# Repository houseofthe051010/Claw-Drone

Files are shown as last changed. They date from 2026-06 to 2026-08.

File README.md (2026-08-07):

# Claw Drone

Claw Drone

This is a payload quadcopter with four continuous-rotation claw
servos to grab objects. I build a custom controller with
two joysticks, trim buttons, a TFT dashboard, and direct claw controls.
The transmitter uses ESPNOW long range to send CRSF commands at 200hz, where another RX es32 onboard converts them into CRSF for the FC to interpret.

I built this as a way to further myself in the knowledge of drones and aerial payload delivery.

The CAD, BOM, and FIRMWARE for both the controller and the drone are in this repo

This project started with an esp32 as the FC, but later changed to using a conventional ESC+FC stack.

## Demo

[Watch the competition flight demo on YouTube](https://youtube.com/shorts/Rw3jiggKQBY)

## System architecture

```text
Joysticks and buttons
        |
        v
Black Pill Pico-compatible board -- UART 115200 --> Controller ESP32-WROOM
                                           |
                                           | ESP-NOW LR, channel 6
                                           v
                                    Drone ESP32-WROOM
                                      |           |
                           CRSF UART3 |           | 4 x 50 Hz PWM
                                      v           v
                              Betaflight FC    Claw servos
                                      |
                                      v
                                ESC and motors
```

## Wiring schematics

### Handheld controller schematic

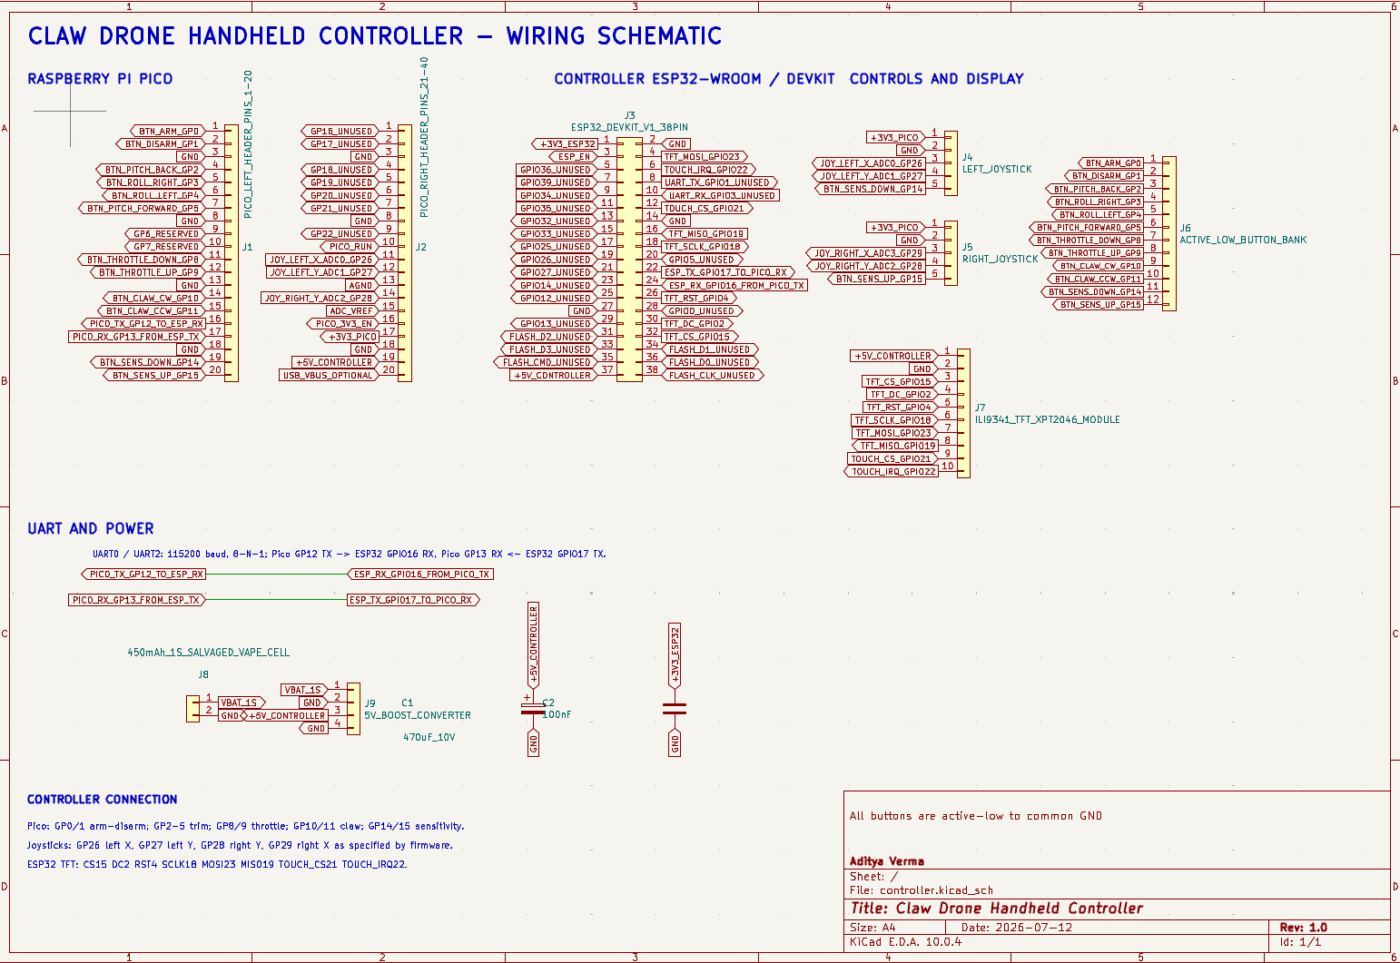
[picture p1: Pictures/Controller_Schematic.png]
Handheld controller wiring schematic


### Aircraft schematic

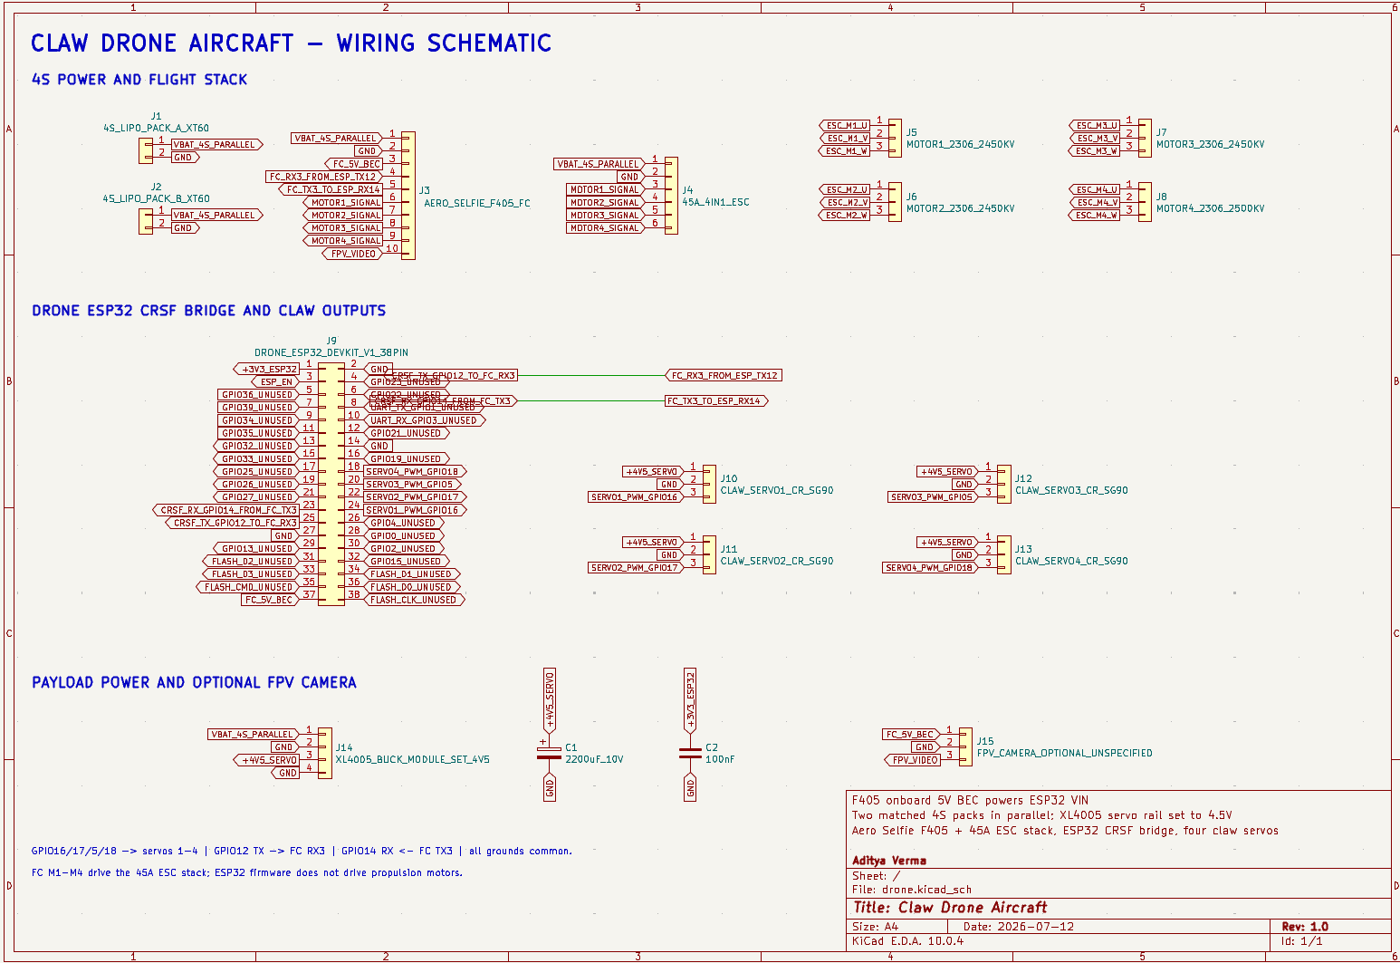
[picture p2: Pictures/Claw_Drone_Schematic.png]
Aircraft wiring schematic


## Bill of materials

| Assembly |  Quantity | Part | Purchase Link | Estimated Price |
| --- | ---: | --- | --- | ---: |
| Aircraft | 1 | Frame | [AliExpress](https://www.aliexpress.us/item/3256811569379527.html) | $17.06 |
| Aircraft | 1 | FC + ESC stack | [AliExpress](https://www.aliexpress.us/item/3256808946065124.html) | $49.63 |
| Aircraft | 4 | Brushless motors | [AliExpress](https://www.aliexpress.us/item/3256812458735650.html) | $61.36 |
| Aircraft | 1 set | Propellers | [AliExpress](https://www.aliexpress.us/item/2255801043927518.html) | $15.25 |
| Aircraft | 2 | Flight batteries | [AliExpress](https://www.aliexpress.us/item/3256812540292605.html) | $30.34 |
| Aircraft | 1 | XT60 connectors | [AliExpress](https://www.aliexpress.us/item/3256807605726245.html) | $1.77 |
| Aircraft | 1 | ESP32 | [AliExpress](https://www.aliexpress.us/item/3256808984038785.html) | $4.84 |
| Aircraft | 4 | Servos | [AliExpress](https://www.aliexpress.us/item/3256809795714797.html) | $3.63 used |
| Aircraft | 1 | XL4005 buck converter | [AliExpress](https://www.aliexpress.us/item/3256806558389509.html) | $1.46 |
| Aircraft | 1 | Camera | [AliExpress](https://www.aliexpress.us/item/3256810060131517.html) | $25.90 |
| Aircraft | 1 | 3D-printing allowance | [AliExpress](https://www.aliexpress.us/item/3256806989098121.html) | $2.54 |
| Aircraft | As needed | Wiring | [AliExpress](https://www.aliexpress.us/item/3256809610137308.html) | $5.49 allowance |
| Aircraft | As needed | Connectors | [AliExpress](https://www.aliexpress.us/item/3256804089626824.html) | $3.81 assortment kit |
| Controller | 1 | Raspberry Pi Pico | [AliExpress](https://www.aliexpress.us/item/3256805910466139.html) | $4.35 |
| Controller | 1 | ESP32 | [AliExpress](https://www.aliexpress.us/item/3256808984038785.html) | $4.84 |
| Controller | 1 | TFT touchscreen display | [AliExpress](https://www.aliexpress.us/item/2255800128937536.html) | $10.87 |
| Controller | 2 | Joystick modules | [AliExpress](https://www.aliexpress.us/item/3256809884616435.html) | $5.76 |
| Controller | 10 | Pushbuttons | [AliExpress](https://www.aliexpress.us/item/3256801710165519.html) | $3.32 |
| Controller | 1 | Controller battery | [AliExpress](https://www.aliexpress.us/item/3256809090690409.html) | $4.24 |
| Controller | 1 | Boost converter | [AliExpress](https://www.aliexpress.us/item/3256810344563800.html) | $0.99 |
| Controller | 1 | TP4056 charger module | [AliExpress](https://www.aliexpress.us/item/3256808777213556.html) | $0.20 used |
| Controller | 1 | Power switch | [AliExpress](https://www.aliexpress.us/item/3256807619399290.html) | $0.16 used |
| Controller | 1 | Bulk capacitor | [AliExpress](https://www.aliexpress.us/item/2251832671851361.html) | $0.10 used |
| Controller | 1 | Decoupling capacitor | [AliExpress](https://www.aliexpress.us/item/3256811560978404.html) | $0.01 used |
| Controller | 1 | Controller filament allowance | [AliExpress](https://www.aliexpress.us/item/3256806989098121.html) | $3.04 |
| Controller | As needed | Wiring | [AliExpress](https://www.aliexpress.us/item/3256809610137308.html) | $5.49 allowance |

## Assembly process

### Print settings

The prototype was printed in PETG on an Anycubic Kobra S1 using 100% infill,
10 walls, and a 0.2 mm layer height. The printable files are in
[`CAD/Individual STL files`](CAD/Individual%20STL%20files), with matching STEP
exports in [`CAD/Individual STEP files`](CAD/Individual%20STEP%20files).

Use [Building Your First 5-Inch FPV Drone: A Complete Step-by-Step Guide](https://blog.uavmodel.com/building-your-first-5-inch-fpv-drone-a-complete-step-by-step-guide/) for the standard FPV frame/motor/ESC+FC stack guide.

### Aircraft build

1. Build it like a normal FPV frame, like the one in the video above
  * If you have a commercial FPV frame that will work, otherwise print the frame pieces in the INDIVIDUAL STLs

2. Parallel battery connection
 
Solder two XT60 connectors; you don't even need to do this if you don't want to, as it only increases flight time while increasing weight too. Keep following what the demo video does if you don't want a parallel connection. If you do then you have to solder two XT60 wires to the ESC -/+ pads.

3. Standard FPV connections
Plug the ESP32 U.FL Wroom into the F405 5 V BEC and common ground.
This is your version of the "ELRS" the demo ideo will be talking about. Connect TX3/RX3 to esp32 RX2/TX2.
Also, for the camera you won't be using that 5.8ghz or DJI O4 mini. You will use the xiao S3 mini cam, and connect the 5V BEC and common gnd just like you did with the RX esp32.

4. Four-servos claw
3D print four SG90 mount holders and install one beneath each motor holder.
 * This is inside the Additional Attachment individual STLs, print the mirrored and normal servo claw attachment twice (4 total)
 * Also print the servo mounts to mount them with the motor mounts
Install the 10mm M3s to mount them and secure each SG90 servo to its printed holder with the self-tapping screws.
Route the servo cables along the arms to the inside. Secure them outside the motor and propeller area with zip ties.
Connect all four servo positive wires to XL4005 OUT+, and all four grounds to OUT-. Connect the PWM control lines as servo 1 – GPIO16, servo 2 – GPIO17, servo 3 – GPIO5, and servo 4 – GPIO18.

5. XL4005 claw power supply
Connect XL4005 IN+ directly to the ESC BAT+ pad and IN- to BAT-.
Make sure to set the voltage to 4.5v Connect all four servos to a common gnd with the esp32.

### Handheld controller build

1. Enclosure preparation
Print all of the INDIVIDUAL STLs, get soldering iron, flux, and a ton of thin 32AWG wire

2. Controller power supply
Mount the LIPO cell with glue.
Mount the TP4056 next to its usb port hole on the case
Connect the battery to TP4056 B+ and B-. Then, connect TP4056 OUT+ to the main toggle switch, while OUT- connects to controller ground.
Make sure its outputting 5v

3. Controller boards and antenna
Position the Black Pill board right behind the USB opening of the enclosure.
Apply glue to the flat underside of the board to mount it there.
Mount the controller ESP32 right to the left of the Black Pill board using adhesive on its flat side.
The UART connection runs from Black Pill GP12 TX to ESP32 GPIO16 RX and from Black Pill GP13 RX to ESP32 GPIO17 TX.
Install the U.FL antenna, and glue it to the top center opening.

4. Buttons
Use superglue to secure buttons.
Daisy change the grounds (easiest way to avoid messy wiring)
Connect the other terminals to their respective pi pico GPIO

5. Joysticks
Secure each joystick in its four mounting holes
Connect their 3.3/GND to pi pico, and their ADC pins to the assigned ADC gpio.

6. TFT display
Solder the ESP32 to the TFT as CS GPIO15, DC GPIO2, RST GPIO4, SCLK GPIO18, MOSI GPIO23, MISO GPIO19, touch CS GPIO21, and touch IRQ GPIO22.
TFT power connects to the regulated 5V rail.
Mount it with M3 x 25 mm screws, and route its wires to the left of the pi pico (make sure they are short or it will be hard).

## Controller pinout

USE THIS WHEN BUILDING THE CONTROLLER/DRONE

### Black Pill Picoboard

Note that you have to be using a black pill pico with 4 ADC inputs instead of 3 like the normal pi pico.

| Pico pin | Connection |
| --- | --- |
| GP0 | Button to GND |
| GP1 | Button to GND |
| GP2 | Button to GND |
| GP3 | Button to GND |
| GP4 | Button to GND |
| GP5 | Button to GND |
| GP6 | Not used |
| GP7 | Not used |
| GP8 | Button to GND |
| GP9 | Button to GND |
| GP10 | Button to GND |
| GP11 | Button to GND |
| GP12 | ESP32 GPIO16 |
| GP13 | ESP32 GPIO17 |
| GP14 | Left stick button |
| GP15 | Right stick button |
| GP25 | Onboard LED |
| GP26 / ADC0 | Left joystick X |
| GP27 / ADC1 | Left joystick Y |
| GP28 / ADC2 | Right joystick Y |
| GP29 / ADC3 | Right joystick X |
| 3V3 | Joystick VCC |
| GND | All controller grounds |

### Pico to controller ESP32 UART

| Black Pill Pico-compatible board | Controller ESP32-WROOM |
| --- | --- |
| GP12 UART0 TX | GPIO16 UART2 RX |
| GP13 UART0 RX | GPIO17 UART2 TX |
| GND | GND |

### Controller TFT and touch

| Display signal | Controller ESP32 GPIO |
| --- | --- |
| TFT CS | GPIO15 |
| TFT DC | GPIO2 |
| TFT RST | GPIO4 |
| SPI SCLK | GPIO18 |
| SPI MOSI | GPIO23 |
| SPI MISO | GPIO19 |
| Touch CS | GPIO21 |
| Touch IRQ | GPIO22 |
| GND | GND |

## Four-leg claw system

You have to use the self tapping screws that came with the sg90 to mount them.

1. Legs spread from the center creating area around the payload.
2. All four legs move out from under the motors.

## Drone pinout

### Drone ESP32 to Betaflight flight controller

| Drone ESP32-WROOM | Flight controller |
| --- | --- |
| GPIO12 UART2 TX | RX3 |
| GPIO14 UART2 RX | TX3 |
| GND | GND |

UART setup for CRSF protocol.

### Drone ESP32 servo outputs

| Servo | PWM signal pin |
| --- | --- |
| Servo 1 | ESP32 GPIO16 |
| Servo 2 | ESP32 GPIO17 |
| Servo 3 | ESP32 GPIO5 |
| Servo 4 | ESP32 GPIO18 |

The FC did not have enough motor outputs to drive servos so I used the onboard ESP32.

### Servo power

Servos are powered by the XL4005 buck converter at 4.5V

## Setting up the code

Use the PlatformIO extension in VScode to flash, configure this repo with it and run this in terminal:

### Flashing the controller ESP32

```sh
cd Code/controller/esp32_tx
pio run -t upload
pio device monitor
```

### Flashing the drone ESP32

```sh
cd Code/drone/esp32_rx
pio run -t upload
pio device monitor
```

Flash using micropython for the rpi, flash it with thonny using main.py code from Code/controller/pico/main.py

On the drone use ESP-IDF, the flight controller uses betaflight

The code is in the repo folder

Every ESP32 has different values for this: 

| Device | Wi-Fi STA MAC |
| --- | --- |
| Controller ESP32 | `68:09:47:5c:04:c4` |
| Drone ESP32 | `68:09:47:5c:2f:8c` |

Update both hard-coded peer addresses as per your devices.

* `drone_mac` in
  `Code/controller/esp32_tx/main/main.c`
* `controller_mac` in
  `Code/drone/esp32_rx/main/main.c`

## Betaflight setup

Give CRSF on UART3 with this configuration:

```text
serial 1 0 115200 57600 0 115200
serial 2 64 115200 57600 0 115200
set serialrx_provider = CRSF
set serialrx_inverted = OFF
set serialrx_halfduplex = OFF
save
```

| CRSF channel | Function |
| --- | --- |
| CH1 | Roll |
| CH2 | Pitch |
| CH3 | Throttle |
| CH4 | Yaw |
| CH5 / AUX1 | Arm |
| CH6 / AUX2 | Link-active indication |

ARM mode uses AUX1.

## Design and build process

### 1. Early arm concepts

First design concept was X-frame design with 5-DoF arm.
It has been dropped because of the arm mass. Second design concept was a
frame with electronics placed near its perimeter, and an opening in its center like a DONUT.
Through this opening, servo-controlled rope and spring mechanism were going
to clamp the payload. This was abandoned though as it interfered with the rotor thrust.

### 2. Lightweight claw redesign

I had four servos underneath, and initially a 5 dof arm as the claw.

Early claw prototype

Redesigned claw CAD

### 3. ESP32 flight-controller experiment

I used a esp32 supermini S3 but there were problems with the ESC connection and FC espnow connection leading me to abondon it.

ESP32 and ESC development

### 4. Moving flight control to Betaflight

Switched from ESP32 FC + cheap rc airplane ESCs to conventional drone stack.

Flight-controller stack

### 5. Building the custom transmitter

NRF24L01 were used at first but I switched to ESPNOW as its less wiring and reliable.

Transmitter wiring

Completed transmitter

### 6. Final assembly

Everything connected together

Final electronics assembly

Drone with claw installed

## What I would change next time\

* Improve the claw mehanism
* Have a single strong motor for the claw
* Increase drone size
* Have a much more robust FC

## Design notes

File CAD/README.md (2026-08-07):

# CAD files

## Print settings

The prototype was printed in PETG on an Anycubic Kobra S1 using:

- 100% infill
- 10 walls
- 0.2 mm layer height

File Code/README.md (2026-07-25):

# Firmware

```text
controller/
  pico/
    main.py              Reads controls and sends framed UART packets
  esp32_tx/
    main/main.c          UART bridge, ESP-NOW, servo web server
    main/dashboard.c     TFT dashboard and telemetry display
drone/
  esp32_rx/
    main/main.c          ESP-NOW receiver, CRSF output, servo PWM
diagnostics/
  pico_joystick_button_test/
    main.py              Standalone Pico input test
```

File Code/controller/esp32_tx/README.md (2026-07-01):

# Controller ESP32: Pico UART to ESP-NOW

This is the controller-side ESP32-WROOM bridge.

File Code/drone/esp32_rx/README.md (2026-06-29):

# Drone ESP32: ESP-NOW to CRSF receiver

This is the drone-side receiver. It receives control frames over
ESP-NOW and outputs CRSF RC frames to the flight controller.

Wiring:

| ESP32 WROOM | Flight controller |
| --- | --- |
| GPIO12 TX | FC RX3 |
| GPIO14 RX | FC TX3 |
| GND | GND |

Both ESP32s use unicast ESP-NOW on Wi-Fi channel 6 with Espressif Long Range
PHY at 250 Kbit/s. The transmitter is configured for this receiver's STA MAC:
`68:09:47:5c:2f:8c`.

The FC TX3 return wire is parsed for CRSF battery sensor frames. Valid battery
voltage and remaining-capacity percentage are returned to controller STA MAC
`68:09:47:5c:04:c4` over ESP-NOW for the TFT dashboard. No estimate is shown
when the FC does not provide a valid battery telemetry frame.

This firmware drives four direct ESP32 servo outputs at 50 Hz. They start
centered at 1500 us:

| Servo | ESP32 GPIO |
| --- | --- |
| Servo 1 | GPIO16 |
| Servo 2 | GPIO17 |
| Servo 3 | GPIO5 |
| Servo 4 | GPIO18 |

The matching transmitter web interface sends separate CRC-protected continuous
servo packets. Each output accepts 500-2500 us and applies a new pulse width
immediately. Saved neutral values and the selected 10-500 us rotation stretch
are stored in NVS and restored before PWM starts after a reboot. If servo
commands stop for 1.5 seconds, every output returns to its saved neutral value.

Betaflight UART3 configuration:

```text
serial 1 0 115200 57600 0 115200
serial 2 64 115200 57600 0 115200
set serialrx_provider = CRSF
set serialrx_inverted = OFF
set serialrx_halfduplex = OFF
save
```

`GPIO12` is an ESP32 boot-strapping pin. The FC RX input should be
high-impedance, but an external pull-up on this signal can prevent the ESP32
from booting. If that occurs, disconnect GPIO12 during reset or move CRSF TX
to a non-strapping GPIO and update `CRSF_TX_PIN`.

Build/flash:

```sh
cd Code/drone/esp32_rx
pio run -t upload
pio device monitor
```

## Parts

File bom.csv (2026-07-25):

Assembly | Quantity | Part | Link | Price
Aircraft | 1 | frame | https://www.aliexpress.us/item/3256811569379527.html | $17.06
Aircraft | 1 | FC+ESC stack | https://www.aliexpress.us/item/3256808946065124.html | $49.63
Aircraft | 4 | Brushless motor | https://www.aliexpress.us/item/3256812458735650.html | $61.36
Aircraft | 1 set | Propellers | https://www.aliexpress.us/item/2255801043927518.html | $15.25
Aircraft | 2 | Flight battery | https://www.aliexpress.us/item/3256812540292605.html | $30.34
Aircraft | 1 | XT60 connectors | https://www.aliexpress.us/item/3256807605726245.html | $1.77
Aircraft | 1 | ESP32 | https://www.aliexpress.us/item/3256808984038785.html | $4.84
Aircraft | 4 | servo | https://www.aliexpress.us/item/3256809795714797.html | $3.63 used (4 of 5-pack at $4.54)
Aircraft | 1 | XL4005 buck | https://www.aliexpress.us/item/3256806558389509.html | $1.46
Aircraft | 1 | Camera | https://www.aliexpress.us/item/3256810060131517.html | $25.90
Aircraft | 1 | 3d print allowance | https://www.aliexpress.us/item/3256806989098121.html | $2.54
Aircraft | as needed | wiring | https://www.aliexpress.us/item/3256809610137308.html | $5.49 allowance
Aircraft | as needed | connectors | https://www.aliexpress.us/item/3256804089626824.html | $3.81 assortment kit
Controller | 1 | pi pico | https://www.aliexpress.us/item/3256805910466139.html | $4.35
Controller | 1 | ESP32 | https://www.aliexpress.us/item/3256808984038785.html | $4.84
Controller | 1 | TFT touch display | https://www.aliexpress.us/item/2255800128937536.html | $10.87
Controller | 2 | Joystick module | https://www.aliexpress.us/item/3256809884616435.html | $5.76
Controller | 10 | pushbutton | https://www.aliexpress.us/item/3256801710165519.html | $3.32
Controller | 1 | Controller battery | https://www.aliexpress.us/item/3256809090690409.html | $4.24
Controller | 1 | Boost converter | https://www.aliexpress.us/item/3256810344563800.html | $0.99
Controller | 1 | TP4056 | https://www.aliexpress.us/item/3256808777213556.html | $0.20 used
Controller | 1 | power switch | https://www.aliexpress.us/item/3256807619399290.html | $0.16 used
Controller | 1 | Bulk capacitor | https://www.aliexpress.us/item/2251832671851361.html | $0.10 used
Controller | 1 | Decoupling capacitor | https://www.aliexpress.us/item/3256811560978404.html | $0.01 used
Controller | 1 | Controller filament allowance | https://www.aliexpress.us/item/3256806989098121.html | $3.04
Controller | as needed | wiring | https://www.aliexpress.us/item/3256809610137308.html | $5.49 allowance

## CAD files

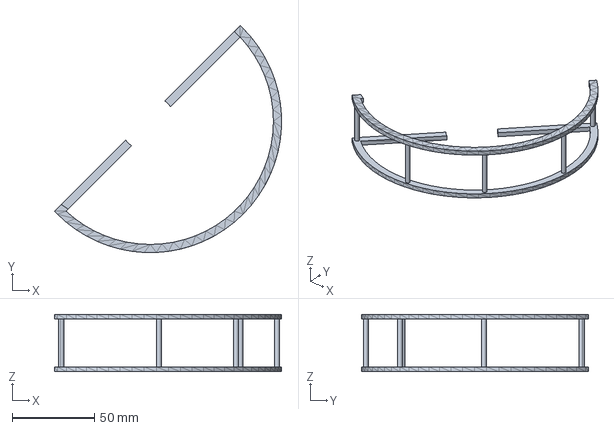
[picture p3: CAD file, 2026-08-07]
CAD/Individual STEP files/Attachment Parts/PROP_GUARD.step
138.3 x 138.3 x 35.0 mm

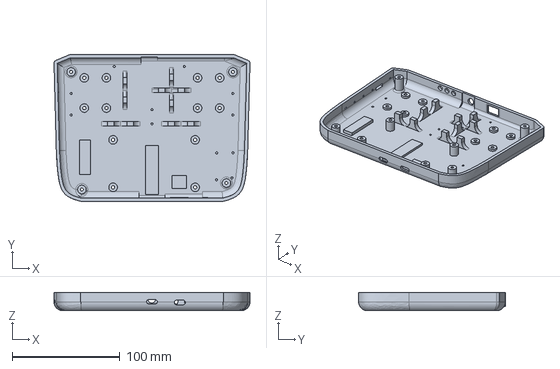
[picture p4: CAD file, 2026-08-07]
CAD/Individual STEP files/Controller/Bottom Plate.step
181.7 x 136.0 x 17.0 mm

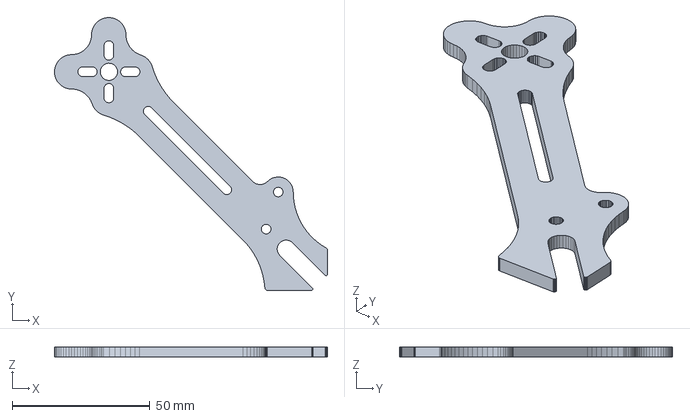
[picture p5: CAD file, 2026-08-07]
CAD/Individual STEP files/Drone Frame/Frame Arm (3).step
99.0 x 99.0 x 3.50 mm

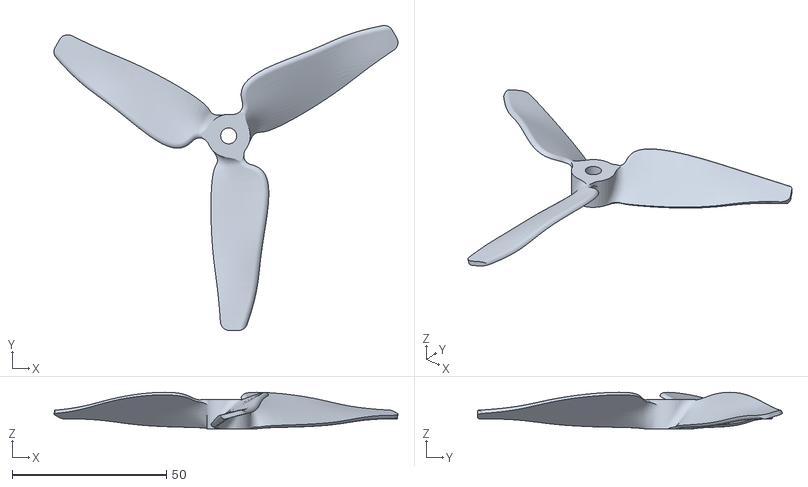
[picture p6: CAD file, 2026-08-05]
CAD/Individual STL files/Attachment Parts/5 inch propellors.stl
111.4 x 98.7 x 11.8

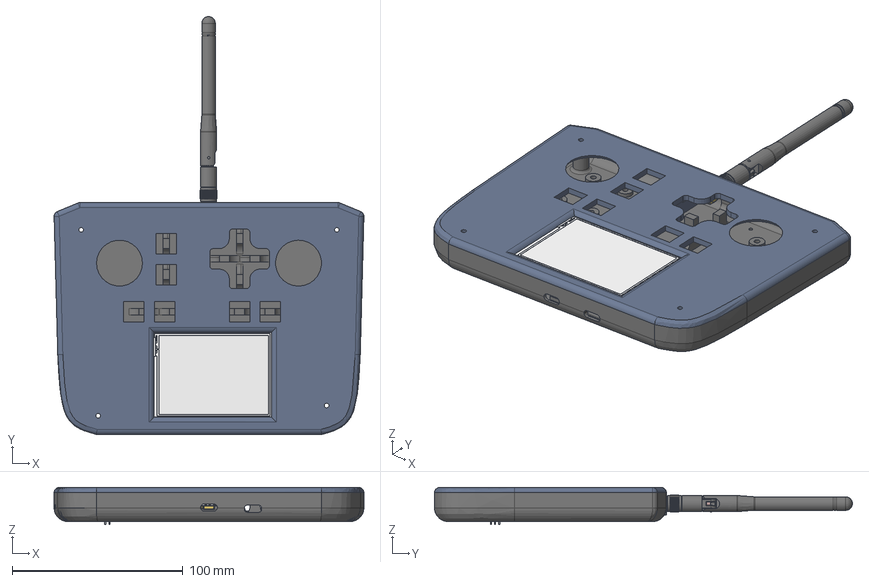
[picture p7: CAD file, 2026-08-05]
CAD/SOURCE Cad/Drone Controller.step
181.7 x 245.2 x 21.7 mm

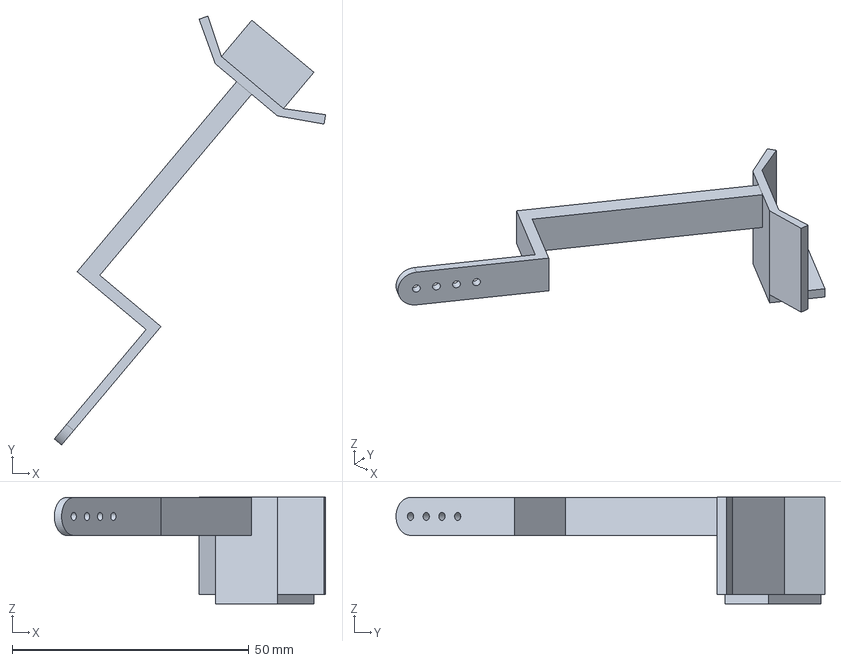
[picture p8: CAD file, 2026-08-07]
CAD/Individual STEP files/Attachment Parts/Servo Claw Attachment Pt2 (Mirrored).step
57.3 x 90.6 x 22.5 mm

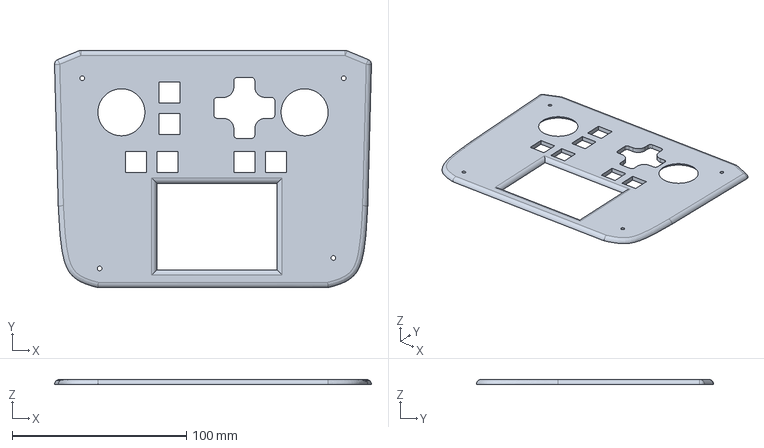
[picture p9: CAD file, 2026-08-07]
CAD/Individual STEP files/Controller/Top Plate.step
181.7 x 136.0 x 3.00 mm

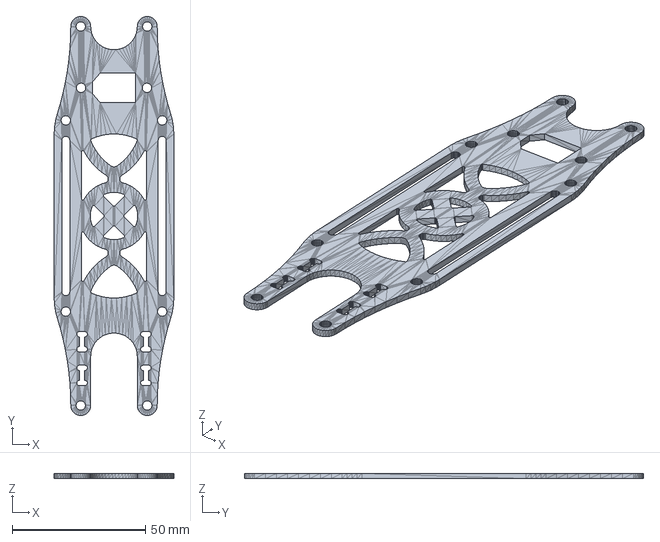
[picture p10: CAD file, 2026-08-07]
CAD/Individual STEP files/Drone Frame/Bottom Plate.step
45.0 x 150.0 x 2.00 mm

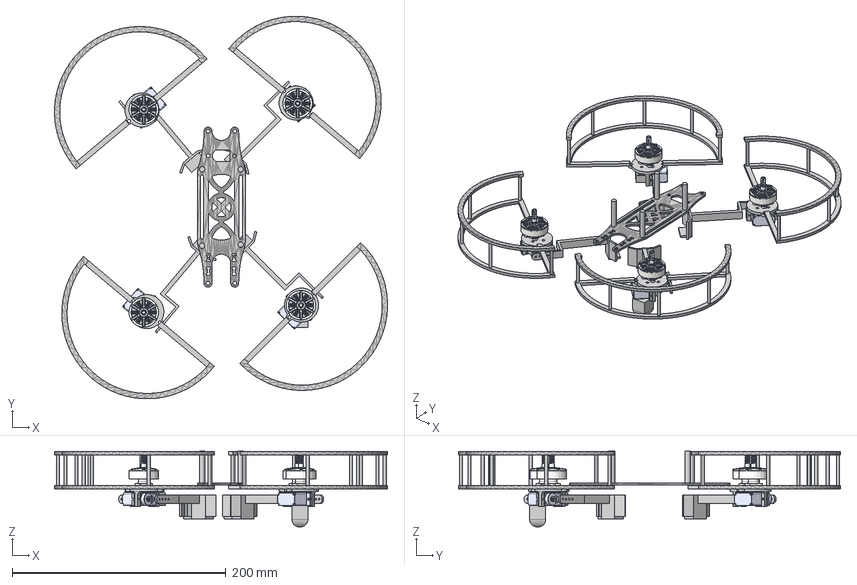
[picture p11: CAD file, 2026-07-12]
CAD/SOURCE Cad/Claw Drone.step
311.9 x 358.2 x 71.1 mm

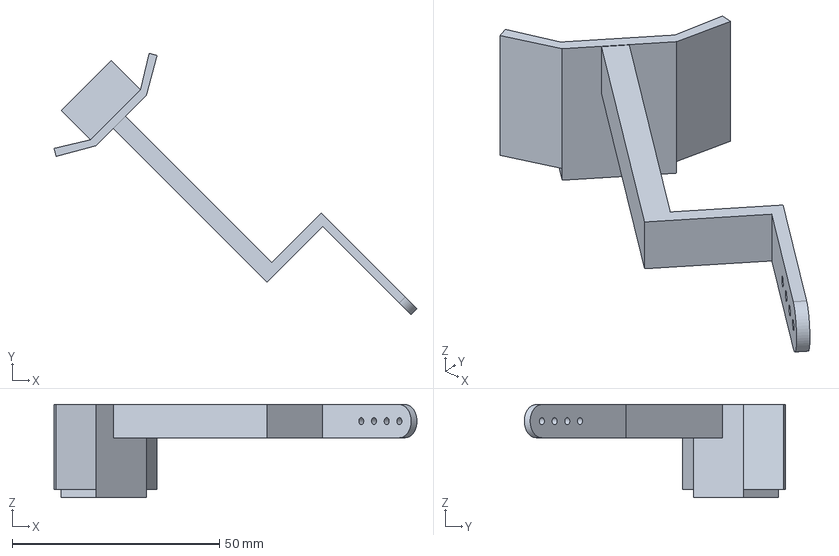
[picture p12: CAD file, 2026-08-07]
CAD/Individual STEP files/Attachment Parts/Servo Claw Attachment Pt1.step
87.5 x 63.0 x 22.5 mm

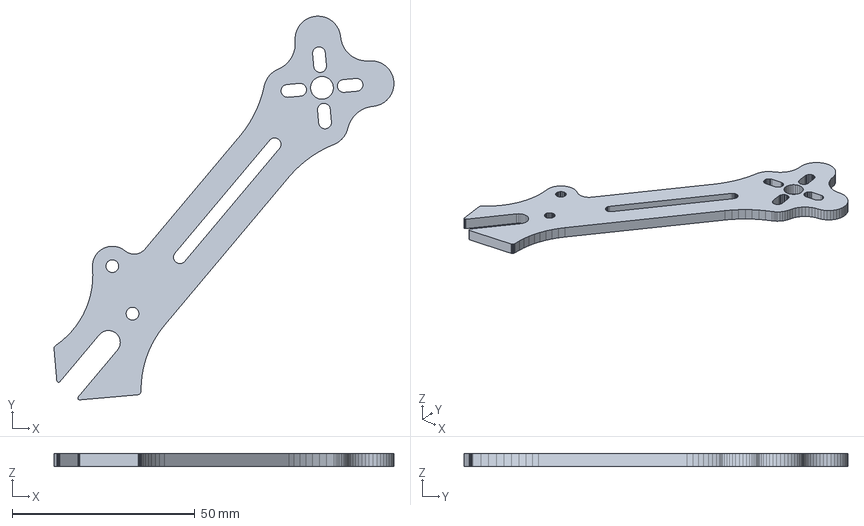
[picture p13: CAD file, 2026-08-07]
CAD/Individual STEP files/Drone Frame/Frame Arm (2).step
93.1 x 105.0 x 3.50 mm

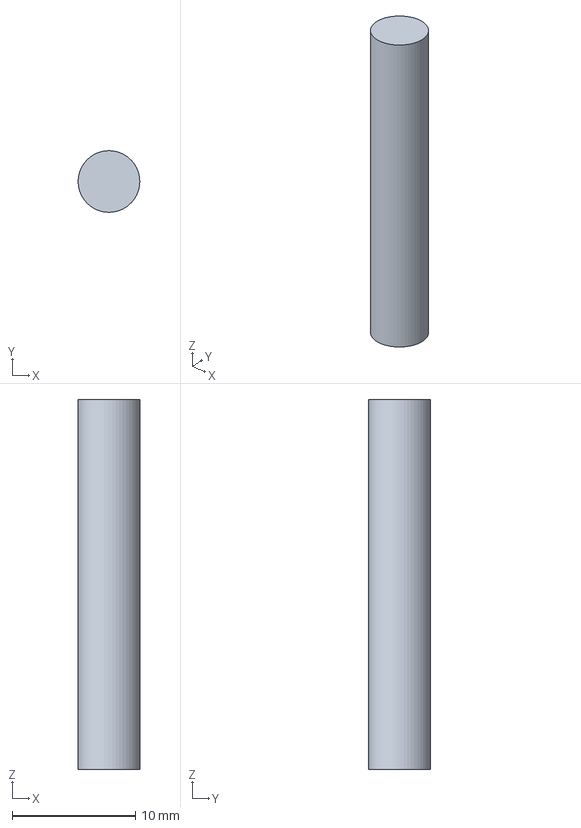
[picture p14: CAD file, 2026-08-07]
CAD/Individual STEP files/Drone Frame/M3 Spacers.step
5.00 x 5.00 x 30.0 mm

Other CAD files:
CAD/Individual STEP files/Drone Frame/Frame Arm (1).step
CAD/Individual STEP files/Drone Frame/Top Plate.step
CAD/Individual STEP files/Drone Frame/Frame Arm (4).step
CAD/Individual STL files/Attachment Parts/PROP_GUARD.stl
CAD/Individual STL files/Attachment Parts/Servo Claw Attachment Pt1.stl
CAD/Individual STL files/Attachment Parts/Servo Claw Attachment Pt2 (Mirrored).stl
CAD/Individual STL files/Controller/Bottom Plate.stl
CAD/Individual STL files/Controller/Top Plate.stl
CAD/Individual STL files/Drone Frame/Bottom Plate.stl
CAD/Individual STL files/Drone Frame/Frame Arm (1).stl
CAD/Individual STL files/Drone Frame/Frame Arm (2).stl
CAD/Individual STL files/Drone Frame/Frame Arm (3).stl
CAD/Individual STL files/Drone Frame/Frame Arm (4).stl
CAD/Individual STL files/Drone Frame/M3 Spacers.stl
CAD/Individual STL files/Drone Frame/Top Plate.stl

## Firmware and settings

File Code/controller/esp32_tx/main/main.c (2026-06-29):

#include <stdbool.h>
#include <stdint.h>
#include <stdio.h>
#include <stdlib.h>
#include <string.h>

#include "driver/gpio.h"
#include "driver/uart.h"
#include "esp_event.h"
#include "esp_http_server.h"
#include "esp_log.h"
#include "esp_mac.h"
#include "esp_netif.h"
#include "esp_now.h"
#include "esp_timer.h"
#include "esp_wifi.h"
#include "freertos/FreeRTOS.h"
#include "freertos/queue.h"
#include "freertos/task.h"
#include "nvs.h"
#include "nvs_flash.h"

#include "dashboard.h"

#define WIFI_CHANNEL 6
#define AP_SSID "Drone-Servo-TX"
#define AP_PASSWORD "servo-control"

#define PICO_UART UART_NUM_2
#define PICO_UART_TX_PIN GPIO_NUM_17
#define PICO_UART_RX_PIN GPIO_NUM_16
#define PICO_UART_BAUD_RATE 115200

#define UART_SYNC_0 0xA5
#define UART_SYNC_1 0x5A
#define CONTROL_PAYLOAD_SIZE 16
#define RADIO_PACKET_MAGIC 0x52
#define RADIO_PACKET_VERSION 1
#define SERVO_PACKET_MAGIC 0x53
#define CONTROLLER_STATUS_MAGIC 0x54
#define TELEMETRY_PACKET_MAGIC 0x55
#define CONTROLLER_SERVO_MAGIC 0x56
#define SERVO_COUNT 4
#define SERVO_MIN_US 500
#define SERVO_MAX_US 2500
#define SERVO_DEFAULT_US 1500
#define SERVO_RAMP_MIN_US_S 10
#define SERVO_RAMP_MAX_US_S 500
#define SERVO_RAMP_DEFAULT_US_S 250
#define SERVO_KEEPALIVE_US 1000000
#define SERVO_RETRY_US 20000
#define CONTROLLER_SERVO_TIMEOUT_US 350000
#define SERVO_FLAG_SAVE_DEFAULTS (1U << 0)
#define SERVO_NVS_NAMESPACE "servo"
#define SERVO_NVS_KEY "config"

#define CONTROL_FLAG_ARM (1U << 0)
#define CONTROL_FLAG_ESTOP (1U << 1)
#define CONTROL_FLAG_CLEAR_ESTOP (1U << 2)

static const char *TAG = "pico_espnow_tx";
// Drone ESP32-WROOM STA MAC, read from the verified onboard receiver.
static const uint8_t drone_mac[ESP_NOW_ETH_ALEN] = {
    0x68, 0x09, 0x47, 0x5c, 0x2f, 0x8c,
};

static uint32_t uart_good;
static uint32_t uart_bad;
static uint32_t uart_status;
static uint32_t uart_servo;
static uint32_t espnow_queued;
static uint32_t espnow_failed;
static uint32_t espnow_delivered;
static uint32_t espnow_lost;
static uint16_t last_sequence;
static QueueHandle_t send_result_queue;
static portMUX_TYPE servo_mux = portMUX_INITIALIZER_UNLOCKED;
static uint16_t servo_values[SERVO_COUNT] = {
    SERVO_DEFAULT_US, SERVO_DEFAULT_US, SERVO_DEFAULT_US, SERVO_DEFAULT_US,
};
static uint16_t servo_ramp_speed_us_s = SERVO_RAMP_DEFAULT_US_S;
static uint16_t servo_startup_values[SERVO_COUNT] = {
    SERVO_DEFAULT_US, SERVO_DEFAULT_US, SERVO_DEFAULT_US, SERVO_DEFAULT_US,
};
static uint16_t servo_startup_ramp_speed_us_s = SERVO_RAMP_DEFAULT_US_S;
static uint32_t servo_generation;
static uint8_t servo_save_repeats;
static bool controller_servo_active;
static int64_t controller_servo_last_us;

typedef struct {
    uint16_t values[SERVO_COUNT];
    uint16_t ramp_speed_us_s;
} servo_config_t;

static const char servo_page[] =
    "<!doctype html><html><head><meta name=viewport content='width=device-width,initial-scale=1'>"
    "<title>Drone Servos</title><style>"
    "*{box-sizing:border-box}body{font-family:sans-serif;max-width:900px;margin:auto;padding:12px;background:#111;color:#eee}"
    "h1{font-size:1.45rem;margin:8px 0}.servo,.panel{background:#222;padding:12px;margin:10px 0;border-radius:10px}"
    "#controls{display:grid;grid-template-columns:1fr 1fr;gap:8px}.servo{margin:0}"
    "input[type=range]{width:100%}input[type=number]{width:90px;font-size:1rem}"
    "button{border:0;border-radius:10px;font-weight:bold;user-select:none;-webkit-user-select:none;-webkit-touch-callout:none;-webkit-tap-highlight-color:transparent;touch-action:none;outline:none}button:focus{outline:none}"
    ".default{width:100%;padding:16px;background:#2878d0;color:white;font-size:1.05rem}"
    ".drivegrid{display:grid;grid-template-columns:repeat(4,minmax(74px,1fr));gap:8px;margin-top:10px}"
    ".drive{min-height:92px;padding:8px 4px;color:white;font-size:1.25rem}.drive span{display:block;font-size:.72rem;margin-bottom:7px;opacity:.85}.drive:active{filter:brightness(1.35)}"
    ".cw{background:#278a45}.ccw{background:#b34444}"
    "#status{color:#8f8}small{color:#bbb}</style></head><body>"
    "<h1>Continuous Servo Control</h1><p id=status>Loading...</p>"
    "<small>Hold a direction to rotate. Releasing returns that pair to its neutral PWM.</small>"
    "<div class=panel><b>Saved startup / neutral PWM</b><div id=startup>Loading...</div></div>"
    "<div id=controls></div><button class=default onclick='saveDefaults()'>Set Startup Default</button>"
    "<div class=panel><b>Rotation PWM stretch: <span id=rv>250</span> us</b><input id=ramp type=range min=10 max=500 step=10 value=250></div>"
    "<div class=drivegrid><button class='drive cw' data-p=0 data-d=1><span>PAIR 1</span>CW</button><button class='drive ccw' data-p=0 data-d=-1><span>PAIR 1</span>CCW</button><button class='drive cw' data-p=1 data-d=1><span>PAIR 2</span>CW</button><button class='drive ccw' data-p=1 data-d=-1><span>PAIR 2</span>CCW</button></div><script>"
    "const box=document.getElementById('controls'),status=document.getElementById('status');let timer;"
    "for(let i=1;i<=4;i++){box.insertAdjacentHTML('beforeend',`<div class=servo><b>Servo ${i} neutral</b> "
    "<input id=n${i} type=number min=500 max=2500 step=1> us<input id=s${i} type=range min=500 max=2500 step=1></div>`);}"
    "function values(){return [1,2,3,4].map(i=>+document.getElementById('n'+i).value)}"
    "function ramp(){return +document.getElementById('ramp').value}function setRamp(v){document.getElementById('ramp').value=v;document.getElementById('rv').textContent=v}"
    "function setStartup(v,r){document.getElementById('startup').textContent=`S1 ${v[0]} us | S2 ${v[1]} us | S3 ${v[2]} us | S4 ${v[3]} us | Stretch ${r} us`}"
    "function schedule(){clearTimeout(timer);timer=setTimeout(()=>send(values()),120)}"
    "for(let i=1;i<=4;i++){let n=document.getElementById('n'+i),s=document.getElementById('s'+i);"
    "s.oninput=()=>{n.value=s.value;schedule()};n.onchange=()=>{s.value=n.value;schedule()}}"
    "document.getElementById('ramp').oninput=e=>setRamp(e.target.value);"
    "let sending=false,pending=null;async function send(v,save=false){pending={v:[...v],save};if(sending)return;sending=true;while(pending){let c=pending,rs=ramp();pending=null;status.textContent=c.save?'Saving startup defaults...':'Sending...';try{let r=await fetch(`/api/servos?s1=${c.v[0]}&s2=${c.v[1]}&s3=${c.v[2]}&s4=${c.v[3]}&ramp=${rs}${c.save?'&save=1':''}`);"
    "let j=await r.json();if(!r.ok)throw Error(j.error||'request failed');setStartup(j.startup,j.startupRamp);status.textContent=c.save?'Startup defaults saved':'Ready';}catch(e){status.textContent='Error: '+e.message}}sending=false}"
    "function set(v){v.forEach((x,k)=>{document.getElementById('n'+(k+1)).value=x;document.getElementById('s'+(k+1)).value=x})}"
    "const holds=new Map();function driveValues(){let v=values(),dirs=[0,0],stretch=ramp();holds.forEach(h=>dirs[h.p]+=h.d);dirs.forEach((d,p)=>{d=Math.max(-1,Math.min(1,d));let a=p*2;v[a]=Math.max(500,Math.min(2500,v[a]+d*stretch));v[a+1]=Math.max(500,Math.min(2500,v[a+1]-d*stretch))});return v}"
    "function updateDrive(){send(driveValues())}function stop(e){if(holds.delete(e.pointerId))updateDrive();e.currentTarget.blur()}function stopAll(){if(holds.size){holds.clear();send(values())}}"
    "function saveDefaults(){stopAll();send(values(),true)}"
    "document.querySelectorAll('[data-p]').forEach(b=>{b.onpointerdown=e=>{e.preventDefault();try{b.setPointerCapture(e.pointerId)}catch(x){}holds.set(e.pointerId,{p:+b.dataset.p,d:+b.dataset.d});updateDrive()};b.onpointerup=stop;b.onpointercancel=stop;b.onlostpointercapture=e=>{if(holds.has(e.pointerId))stop(e)};b.oncontextmenu=e=>e.preventDefault()});"
    "window.addEventListener('blur',stopAll);document.addEventListener('visibilitychange',()=>{if(document.hidden)stopAll()});window.addEventListener('pagehide',stopAll);"
    "fetch('/api/servos').then(r=>r.json()).then(j=>{set(j.servos);setRamp(j.ramp);setStartup(j.startup,j.startupRamp);status.textContent='Ready'}).catch(e=>status.textContent='Error: '+e.message);"
    "</script></body></html>";

static uint16_t read_u16_le(const uint8_t *data)
{
    return (uint16_t)data[0] | ((uint16_t)data[1] << 8);
}

static void write_u16_le(uint8_t *data, uint16_t value)
{
    data[0] = (uint8_t)(value & 0xFFU);
    data[1] = (uint8_t)(value >> 8);
}

static int16_t read_i16_le(const uint8_t *data)
{
    return (int16_t)read_u16_le(data);
}

static uint16_t crc16_ccitt(const uint8_t *data, size_t length)
{
    uint16_t crc = 0xFFFF;
    for (size_t i = 0; i < length; ++i) {
        crc ^= (uint16_t)data[i] << 8;
        for (int bit = 0; bit < 8; ++bit) {
            crc = (crc & 0x8000U) ? (uint16_t)((crc << 1) ^ 0x1021U) : (uint16_t)(crc << 1);
        }
    }
    return crc;
}

static bool validate_control_payload(const uint8_t packet[CONTROL_PAYLOAD_SIZE])
{
    if (packet[0] != RADIO_PACKET_MAGIC || packet[15] != RADIO_PACKET_VERSION) {
        return false;
    }

    const uint16_t expected_crc = read_u16_le(&packet[12]);
    const uint16_t actual_crc = crc16_ccitt(packet, 12);
    if (expected_crc != actual_crc) {
        return false;
    }

    const int16_t roll = read_i16_le(&packet[4]);
    const int16_t pitch = read_i16_le(&packet[6]);
    const int16_t throttle = read_i16_le(&packet[8]);
    const int16_t yaw = read_i16_le(&packet[10]);
    if (roll < -1000 || roll > 1000
        || pitch < -1000 || pitch > 1000
        || throttle < 0 || throttle > 1000
        || yaw < -1000 || yaw > 1000) {
        return false;
    }

    return true;
}

static bool apply_controller_status(const uint8_t packet[CONTROL_PAYLOAD_SIZE])
{
    if (packet[0] != CONTROLLER_STATUS_MAGIC
        || packet[1] != RADIO_PACKET_VERSION
        || packet[15] != RADIO_PACKET_VERSION
        || read_u16_le(&packet[12]) != crc16_ccitt(packet, 12)) {
        return false;
    }

    const int16_t roll_trim = read_i16_le(&packet[2]);
    const int16_t pitch_trim = read_i16_le(&packet[4]);
    const int16_t yaw_trim = read_i16_le(&packet[6]);
    const uint16_t throttle = read_u16_le(&packet[8]);
    const uint8_t sensitivity = packet[10];
    const uint8_t armed = packet[11];
    if (roll_trim < -250 || roll_trim > 250
        || pitch_trim < -250 || pitch_trim > 250
        || yaw_trim < -250 || yaw_trim > 250
        || throttle > 1000 || sensitivity < 25 || sensitivity > 100
        || armed > 1) {
        return false;
    }

    dashboard_update_controller(roll_trim, pitch_trim, yaw_trim,
        throttle, sensitivity, armed != 0);
    return true;
}

static uint16_t clamp_servo_us(int32_t value)
{
    if (value < SERVO_MIN_US) {
        return SERVO_MIN_US;
    }
    if (value > SERVO_MAX_US) {
        return SERVO_MAX_US;
    }
    return (uint16_t)value;
}

static bool apply_controller_servo(const uint8_t packet[CONTROL_PAYLOAD_SIZE])
{
    if (packet[0] != CONTROLLER_SERVO_MAGIC
        || packet[1] != RADIO_PACKET_VERSION
        || packet[15] != RADIO_PACKET_VERSION
        || read_u16_le(&packet[12]) != crc16_ccitt(packet, 12)) {
        return false;
    }

    const int8_t direction = (int8_t)packet[2];
    if (direction < -1 || direction > 1) {
        return false;
    }

    portENTER_CRITICAL(&servo_mux);
    for (size_t i = 0; i < SERVO_COUNT; ++i) {
        const int32_t polarity = (i & 1U) == 0 ? 1 : -1;
        const int32_t pulse = (int32_t)servo_startup_values[i]
            + (int32_t)direction * polarity * servo_ramp_speed_us_s;
        servo_values[i] = clamp_servo_us(pulse);
    }
    servo_generation++;
    controller_servo_active = direction != 0;
    controller_servo_last_us = esp_timer_get_time();
    portEXIT_CRITICAL(&servo_mux);
    return true;
}

static void stop_controller_servo_if_timed_out(int64_t now)
{
    if (!controller_servo_active
        || now - controller_servo_last_us <= CONTROLLER_SERVO_TIMEOUT_US) {
        return;
    }

    portENTER_CRITICAL(&servo_mux);
    memcpy(servo_values, servo_startup_values, sizeof(servo_values));
    servo_generation++;
    controller_servo_active = false;
    portEXIT_CRITICAL(&servo_mux);
}

static void receive_callback(const esp_now_recv_info_t *info,
    const uint8_t *data, int length)
{
    if (info == NULL || data == NULL || length != CONTROL_PAYLOAD_SIZE
        || memcmp(info->src_addr, drone_mac, sizeof(drone_mac)) != 0
        || data[0] != TELEMETRY_PACKET_MAGIC
        || data[1] != RADIO_PACKET_VERSION
        || data[15] != RADIO_PACKET_VERSION
        || read_u16_le(&data[12]) != crc16_ccitt(data, 12)) {
        return;
    }

    const uint16_t voltage_mv = read_u16_le(&data[2]);
    const uint8_t remaining_percent = data[4];
    if (data[5] == 0 || voltage_mv < 1000 || voltage_mv > 60000
        || (remaining_percent > 100 && remaining_percent != 255)) {
        return;
    }
    dashboard_update_battery(voltage_mv, remaining_percent);
}

static bool build_servo_payload(uint8_t packet[CONTROL_PAYLOAD_SIZE])
{
    uint16_t values[SERVO_COUNT];
    uint16_t ramp_speed_us_s;
    bool save_defaults;

    portENTER_CRITICAL(&servo_mux);
    memcpy(values, servo_values, sizeof(values));
    ramp_speed_us_s = servo_ramp_speed_us_s;
    save_defaults = servo_save_repeats > 0;
    portEXIT_CRITICAL(&servo_mux);

    memset(packet, 0, CONTROL_PAYLOAD_SIZE);
    packet[0] = SERVO_PACKET_MAGIC;
    packet[1] = save_defaults ? SERVO_FLAG_SAVE_DEFAULTS : 0;
    write_u16_le(&packet[2], ramp_speed_us_s);
    for (size_t i = 0; i < SERVO_COUNT; ++i) {
        write_u16_le(&packet[4 + (i * 2)], values[i]);
    }
    write_u16_le(&packet[12], crc16_ccitt(packet, 12));
    packet[15] = RADIO_PACKET_VERSION;
    return save_defaults;
}

static bool valid_servo_values(const uint16_t values[SERVO_COUNT])
{
    for (size_t i = 0; i < SERVO_COUNT; ++i) {
        if (values[i] < SERVO_MIN_US || values[i] > SERVO_MAX_US) {
            return false;
        }
    }
    return true;
}

static bool valid_ramp_speed(uint16_t ramp_speed_us_s)
{
    return ramp_speed_us_s >= SERVO_RAMP_MIN_US_S
        && ramp_speed_us_s <= SERVO_RAMP_MAX_US_S;
}

static void load_servo_defaults(void)
{
    nvs_handle_t handle;
    if (nvs_open(SERVO_NVS_NAMESPACE, NVS_READONLY, &handle) != ESP_OK) {
        return;
    }
    servo_config_t config;
    size_t length = sizeof(config);
    if (nvs_get_blob(handle, SERVO_NVS_KEY, &config, &length) == ESP_OK
        && length == sizeof(config) && valid_servo_values(config.values)) {
        const uint16_t stretch_us = valid_ramp_speed(config.ramp_speed_us_s)
            ? config.ramp_speed_us_s : SERVO_RAMP_DEFAULT_US_S;
        memcpy(servo_values, config.values, sizeof(config.values));
        servo_ramp_speed_us_s = stretch_us;
        memcpy(servo_startup_values, config.values, sizeof(config.values));
        servo_startup_ramp_speed_us_s = stretch_us;
        ESP_LOGI(TAG, "loaded continuous servo neutrals: %u %u %u %u us stretch=%u us",
            config.values[0], config.values[1], config.values[2], config.values[3],
            stretch_us);
    }
    nvs_close(handle);
}

static esp_err_t save_servo_defaults(const uint16_t values[SERVO_COUNT], uint16_t ramp_speed_us_s)
{
    nvs_handle_t handle;
    esp_err_t result = nvs_open(SERVO_NVS_NAMESPACE, NVS_READWRITE, &handle);
    if (result != ESP_OK) {
        return result;
    }
    const servo_config_t config = {
        .values = {values[0], values[1], values[2], values[3]},
        .ramp_speed_us_s = ramp_speed_us_s,
    };
    result = nvs_set_blob(handle, SERVO_NVS_KEY, &config, sizeof(config));
    if (result == ESP_OK) {
        result = nvs_commit(handle);
    }
    nvs_close(handle);
    return result;
}

static bool servo_query_requests_save(httpd_req_t *request)
{
    const size_t query_length = httpd_req_get_url_query_len(request);
    if (query_length == 0 || query_length > 160) {
        return false;
    }
    char query[161];
    char save[4];
    return httpd_req_get_url_query_str(request, query, sizeof(query)) == ESP_OK
        && httpd_query_key_value(query, "save", save, sizeof(save)) == ESP_OK
        && strcmp(save, "1") == 0;
}

static esp_err_t servo_page_handler(httpd_req_t *request)
{
    httpd_resp_set_type(request, "text/html");
    httpd_resp_set_hdr(request, "Cache-Control", "no-store");
    return httpd_resp_send(request, servo_page, HTTPD_RESP_USE_STRLEN);
}

static bool parse_servo_query(httpd_req_t *request, uint16_t values[SERVO_COUNT],
    uint16_t *ramp_speed_us_s)
{
    const size_t query_length = httpd_req_get_url_query_len(request);
    if (query_length == 0 || query_length > 160) {
        return false;
    }

    char query[161];
    if (httpd_req_get_url_query_str(request, query, sizeof(query)) != ESP_OK) {
        return false;
    }

    for (size_t i = 0; i < SERVO_COUNT; ++i) {
        char key[4];
        char value_text[8];
        snprintf(key, sizeof(key), "s%u", (unsigned)(i + 1));
        if (httpd_query_key_value(query, key, value_text, sizeof(value_text)) != ESP_OK) {
            return false;
        }
        char *end = NULL;
        const long value = strtol(value_text, &end, 10);
        if (end == value_text || *end != '\0' || value < SERVO_MIN_US || value > SERVO_MAX_US) {
            return false;
        }
        values[i] = (uint16_t)value;
    }
    char ramp_text[8];
    if (httpd_query_key_value(query, "ramp", ramp_text, sizeof(ramp_text)) != ESP_OK) {
        return false;
    }
    char *end = NULL;
    const long ramp = strtol(ramp_text, &end, 10);
    if (end == ramp_text || *end != '\0'
        || ramp < SERVO_RAMP_MIN_US_S || ramp > SERVO_RAMP_MAX_US_S) {
        return false;
    }
    *ramp_speed_us_s = (uint16_t)ramp;
    return true;
}

static esp_err_t servo_api_handler(httpd_req_t *request)
{
    uint16_t values[SERVO_COUNT];
    uint16_t ramp_speed_us_s;
    if (httpd_req_get_url_query_len(request) > 0) {
        if (!parse_servo_query(request, values, &ramp_speed_us_s)) {
            httpd_resp_set_status(request, "400 Bad Request");
            httpd_resp_set_type(request, "application/json");
            return httpd_resp_sendstr(request,
                "{\"error\":\"servo neutrals must be 500-2500 and stretch must be 10-500\"}");
        }
        const bool save_defaults = servo_query_requests_save(request);
        if (save_defaults && save_servo_defaults(values, ramp_speed_us_s) != ESP_OK) {
            httpd_resp_set_status(request, "500 Internal Server Error");
            httpd_resp_set_type(request, "application/json");
            return httpd_resp_sendstr(request, "{\"error\":\"failed to save defaults\"}");
        }
        portENTER_CRITICAL(&servo_mux);
        memcpy(servo_values, values, sizeof(values));
        servo_ramp_speed_us_s = ramp_speed_us_s;
        servo_generation++;
        if (save_defaults) {
            memcpy(servo_startup_values, values, sizeof(values));
            servo_startup_ramp_speed_us_s = ramp_speed_us_s;
            servo_save_repeats = 3;
        }
        portEXIT_CRITICAL(&servo_mux);
        ESP_LOGI(TAG, "continuous servo command: %u %u %u %u us stretch=%u us save=%d",
            values[0], values[1], values[2], values[3], ramp_speed_us_s, save_defaults);
    } else {
        portENTER_CRITICAL(&servo_mux);
        memcpy(values, servo_values, sizeof(values));
        ramp_speed_us_s = servo_ramp_speed_us_s;
        portEXIT_CRITICAL(&servo_mux);
    }

    uint16_t startup_values[SERVO_COUNT];
    uint16_t startup_ramp_speed_us_s;
    portENTER_CRITICAL(&servo_mux);
    memcpy(startup_values, servo_startup_values, sizeof(startup_values));
    startup_ramp_speed_us_s = servo_startup_ramp_speed_us_s;
    portEXIT_CRITICAL(&servo_mux);

    char response[192];
    snprintf(response, sizeof(response),
        "{\"servos\":[%u,%u,%u,%u],\"ramp\":%u,"
        "\"startup\":[%u,%u,%u,%u],\"startupRamp\":%u}",
        values[0], values[1], values[2], values[3], ramp_speed_us_s,
        startup_values[0], startup_values[1], startup_values[2], startup_values[3],
        startup_ramp_speed_us_s);
    httpd_resp_set_type(request, "application/json");
    httpd_resp_set_hdr(request, "Cache-Control", "no-store");
    return httpd_resp_sendstr(request, response);
}

static void start_web_server(void)
{
    httpd_config_t config = HTTPD_DEFAULT_CONFIG();
    config.stack_size = 6144;
    httpd_handle_t server = NULL;
    ESP_ERROR_CHECK(httpd_start(&server, &config));

    const httpd_uri_t page = {
        .uri = "/",
        .method = HTTP_GET,
        .handler = servo_page_handler,
    };
    const httpd_uri_t api = {
        .uri = "/api/servos",
        .method = HTTP_GET,
        .handler = servo_api_handler,
    };
    ESP_ERROR_CHECK(httpd_register_uri_handler(server, &page));
    ESP_ERROR_CHECK(httpd_register_uri_handler(server, &api));
    ESP_LOGI(TAG, "Servo web UI: Wi-Fi '%s', password '%s', http://192.168.4.1/",
        AP_SSID, AP_PASSWORD);
}
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
void app_main(void)
{
    esp_err_t result = nvs_flash_init();
    if (result == ESP_ERR_NVS_NO_FREE_PAGES || result == ESP_ERR_NVS_NEW_VERSION_FOUND) {
        ESP_ERROR_CHECK(nvs_flash_erase());
        result = nvs_flash_init();
    }
    ESP_ERROR_CHECK(result);

    load_servo_defaults();
    ESP_LOGI(TAG, "boot Pico UART -> ESP-NOW bridge");
    dashboard_start();
    start_wifi_espnow();
    start_web_server();
    start_pico_uart();

    BaseType_t created = xTaskCreatePinnedToCore(uart_bridge_task, "uart_bridge",
        4096, NULL, 15, NULL, 0);
    ESP_ERROR_CHECK(created == pdPASS ? ESP_OK : ESP_ERR_NO_MEM);
}

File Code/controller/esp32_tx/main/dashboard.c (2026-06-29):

#include "dashboard.h"

#include <stdio.h>
#include <string.h>

#include "driver/gpio.h"
#include "driver/spi_master.h"
#include "esp_check.h"
#include "esp_log.h"
#include "esp_timer.h"
#include "freertos/FreeRTOS.h"
#include "freertos/task.h"

#define TFT_HOST SPI2_HOST
#define TFT_PIN_CS GPIO_NUM_15
#define TFT_PIN_DC GPIO_NUM_2
#define TFT_PIN_RST GPIO_NUM_4
#define TFT_PIN_SCLK GPIO_NUM_18
#define TFT_PIN_MOSI GPIO_NUM_23
#define TFT_PIN_MISO GPIO_NUM_19
#define TOUCH_PIN_CS GPIO_NUM_21
#define TOUCH_PIN_IRQ GPIO_NUM_22

#define TFT_WIDTH 320
#define TFT_HEIGHT 240
#define LINK_TIMEOUT_US 1500000
#define BATTERY_TIMEOUT_US 5000000

#define COLOR_BG 0x0861
#define COLOR_HEADER 0x032C
#define COLOR_PANEL 0x10C3
#define COLOR_PANEL_ALT 0x1945
#define COLOR_WHITE 0xFFFF
#define COLOR_MUTED 0x9CF3
#define COLOR_GREEN 0x07E0
#define COLOR_RED 0xF800
#define COLOR_AMBER 0xFD20
#define COLOR_CYAN 0x07FF

typedef struct {
    int16_t roll_trim;
    int16_t pitch_trim;
    int16_t yaw_trim;
    uint16_t throttle;
    uint16_t battery_mv;
    uint8_t sensitivity;
    uint8_t battery_percent;
    int64_t last_delivery_us;
    int64_t last_battery_us;
    bool armed;
} dashboard_source_t;

typedef struct {
    int16_t roll_trim;
    int16_t pitch_trim;
    int16_t yaw_trim;
    uint16_t throttle;
    uint16_t battery_mv;
    uint8_t sensitivity;
    uint8_t battery_percent;
    bool armed;
    bool connected;
    bool battery_valid;
} dashboard_view_t;

static const char *TAG = "dashboard";
static spi_device_handle_t tft_device;
static spi_device_handle_t touch_device;
static portMUX_TYPE state_mux = portMUX_INITIALIZER_UNLOCKED;
static dashboard_source_t source_state = {
    .sensitivity = 50,
};

static const uint8_t font_rows[][7] = {
    {0, 0, 0, 0, 0, 0, 0},                    // space
    {14, 17, 19, 21, 25, 17, 14},             // 0
    {4, 12, 4, 4, 4, 4, 14},                  // 1
    {14, 17, 1, 2, 4, 8, 31},                 // 2
    {30, 1, 1, 14, 1, 1, 30},                 // 3
    {2, 6, 10, 18, 31, 2, 2},                 // 4
    {31, 16, 16, 30, 1, 1, 30},               // 5
    {14, 16, 16, 30, 17, 17, 14},             // 6
    {31, 1, 2, 4, 8, 8, 8},                   // 7
    {14, 17, 17, 14, 17, 17, 14},             // 8
    {14, 17, 17, 15, 1, 1, 14},               // 9
    {14, 17, 17, 31, 17, 17, 17},             // A
    {30, 17, 17, 30, 17, 17, 30},             // B
    {14, 17, 16, 16, 16, 17, 14},             // C
    {30, 17, 17, 17, 17, 17, 30},             // D
    {31, 16, 16, 30, 16, 16, 31},             // E
    {31, 16, 16, 30, 16, 16, 16},             // F
    {14, 17, 16, 23, 17, 17, 15},             // G
    {17, 17, 17, 31, 17, 17, 17},             // H
    {14, 4, 4, 4, 4, 4, 14},                  // I
    {7, 2, 2, 2, 2, 18, 12},                  // J
    {17, 18, 20, 24, 20, 18, 17},             // K
    {16, 16, 16, 16, 16, 16, 31},             // L
    {17, 27, 21, 21, 17, 17, 17},             // M
    {17, 25, 21, 19, 17, 17, 17},             // N
    {14, 17, 17, 17, 17, 17, 14},             // O
    {30, 17, 17, 30, 16, 16, 16},             // P
    {14, 17, 17, 17, 21, 18, 13},             // Q
    {30, 17, 17, 30, 20, 18, 17},             // R
    {15, 16, 16, 14, 1, 1, 30},               // S
    {31, 4, 4, 4, 4, 4, 4},                   // T
    {17, 17, 17, 17, 17, 17, 14},             // U
    {17, 17, 17, 17, 17, 10, 4},              // V
    {17, 17, 17, 21, 21, 21, 10},             // W
    {17, 17, 10, 4, 10, 17, 17},              // X
    {17, 17, 10, 4, 4, 4, 4},                 // Y
    {31, 1, 2, 4, 8, 16, 31},                 // Z
    {4, 4, 31, 4, 4, 0, 0},                   // +
    {0, 0, 0, 31, 0, 0, 0},                   // -
    {0, 0, 0, 0, 0, 12, 12},                  // .
    {17, 2, 4, 8, 17, 0, 0},                  // %
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
};

static size_t glyph_index(char character)
{
    if (character >= '0' && character <= '9') {
        return 1U + (size_t)(character - '0');
    }
    if (character >= 'A' && character <= 'Z') {
        return 11U + (size_t)(character - 'A');
    }
    switch (character) {
    case '+': return 37;
    case '-': return 38;
    case '.': return 39;
    case '%': return 40;
    case ':': return 41;
    case '/': return 42;
    default: return 0;
    }
}

static void tft_write(bool data_mode, const void *data, size_t length)
{
    gpio_set_level(TFT_PIN_DC, data_mode ? 1 : 0);
    spi_transaction_t transaction = {
        .length = length * 8,
        .tx_buffer = data,
    };
    ESP_ERROR_CHECK(spi_device_polling_transmit(tft_device, &transaction));
}

static void tft_command(uint8_t command)
{
    tft_write(false, &command, 1);
}

static void tft_data(const void *data, size_t length)
{
    tft_write(true, data, length);
}

static void tft_command_data(uint8_t command, const uint8_t *data, size_t length)
{
    tft_command(command);
    if (length > 0) {
        tft_data(data, length);
    }
}
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

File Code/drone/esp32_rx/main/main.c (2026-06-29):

#include <stdbool.h>
#include <stdint.h>
#include <stdio.h>
#include <string.h>

#include "driver/gpio.h"
#include "driver/ledc.h"
#include "driver/uart.h"
#include "esp_event.h"
#include "esp_log.h"
#include "esp_mac.h"
#include "esp_netif.h"
#include "esp_now.h"
#include "esp_timer.h"
#include "esp_wifi.h"
#include "freertos/FreeRTOS.h"
#include "freertos/queue.h"
#include "freertos/task.h"
#include "nvs.h"
#include "nvs_flash.h"

#define WIFI_CHANNEL 6

#define CRSF_UART UART_NUM_2
#define CRSF_TX_PIN GPIO_NUM_12
#define CRSF_RX_PIN GPIO_NUM_14
#define CRSF_BAUD_RATE 420000
#define CRSF_PERIOD_US 6667
#define CONTROL_TIMEOUT_US 500000
#define BEGINNER_ROLL_PITCH_LIMIT 600
#define BEGINNER_YAW_LIMIT 350
#define BEGINNER_THROTTLE_LIMIT 600

#define SERVO_COUNT 4
#define SERVO_CENTER_US 1500
#define SERVO_MIN_US 500
#define SERVO_MAX_US 2500
#define SERVO_PWM_FREQUENCY_HZ 50
#define SERVO_PWM_PERIOD_US 20000
#define SERVO_PWM_TIMER LEDC_TIMER_0
#define SERVO_PWM_MODE LEDC_HIGH_SPEED_MODE
#define SERVO_PWM_RESOLUTION LEDC_TIMER_16_BIT
#define SERVO_RAMP_PERIOD_MS 20
#define SERVO_RAMP_MIN_US_S 10
#define SERVO_RAMP_MAX_US_S 500
#define SERVO_RAMP_DEFAULT_US_S 250
#define SERVO_COMMAND_TIMEOUT_US 1500000
#define SERVO_FLAG_SAVE_DEFAULTS (1U << 0)
#define SERVO_NVS_NAMESPACE "servo"
#define SERVO_NVS_KEY "config"

#define CONTROL_PAYLOAD_SIZE 16
#define RADIO_PACKET_MAGIC 0x52
#define RADIO_PACKET_VERSION 1
#define SERVO_PACKET_MAGIC 0x53
#define TELEMETRY_PACKET_MAGIC 0x55
#define TELEMETRY_SEND_PERIOD_US 500000

#define CONTROL_FLAG_ARM (1U << 0)
#define CONTROL_FLAG_ESTOP (1U << 1)
#define CONTROL_FLAG_CLEAR_ESTOP (1U << 2)

#define CRSF_ADDRESS_FLIGHT_CONTROLLER 0xC8
#define CRSF_FRAME_LENGTH 24
#define CRSF_FRAME_TYPE_RC_CHANNELS_PACKED 0x16
#define CRSF_FRAME_TYPE_BATTERY_SENSOR 0x08
#define CRSF_CHANNEL_MIN 172
#define CRSF_CHANNEL_MID 992
#define CRSF_CHANNEL_MAX 1811
#define CRSF_CHANNEL_COUNT 16
#define CRSF_PAYLOAD_SIZE 22

static const char *TAG = "esp32_espnow_crsf_rx";
static const uint8_t controller_mac[ESP_NOW_ETH_ALEN] = {
    0x68, 0x09, 0x47, 0x5c, 0x04, 0xc4,
};

static const gpio_num_t servo_gpio[SERVO_COUNT] = {
    GPIO_NUM_16,
    GPIO_NUM_17,
    GPIO_NUM_5,
    GPIO_NUM_18,
};

static const ledc_channel_t servo_channel[SERVO_COUNT] = {
    LEDC_CHANNEL_0,
    LEDC_CHANNEL_1,
    LEDC_CHANNEL_2,
    LEDC_CHANNEL_3,
};

typedef struct {
    int16_t roll;
    int16_t pitch;
    int16_t throttle;
    int16_t yaw;
    uint16_t sequence;
    int64_t last_update_us;
    bool arm_requested;
    bool emergency_latched;
} control_state_t;

typedef struct {
    int16_t roll;
    int16_t pitch;
    int16_t throttle;
    int16_t yaw;
    uint16_t sequence;
    int64_t age_us;
    bool arm_requested;
    bool emergency_latched;
    bool link_active;
} control_snapshot_t;

typedef struct {
    uint8_t data[CONTROL_PAYLOAD_SIZE];
} espnow_control_packet_t;

typedef struct {
    uint16_t values[SERVO_COUNT];
    uint16_t ramp_speed_us_s;
} servo_config_t;

static portMUX_TYPE control_mux = portMUX_INITIALIZER_UNLOCKED;
static portMUX_TYPE servo_mux = portMUX_INITIALIZER_UNLOCKED;
static control_state_t control_state = {
    .emergency_latched = true,
};
static uint16_t servo_current[SERVO_COUNT] = {
    SERVO_CENTER_US, SERVO_CENTER_US, SERVO_CENTER_US, SERVO_CENTER_US,
};
static uint16_t servo_target[SERVO_COUNT] = {
    SERVO_CENTER_US, SERVO_CENTER_US, SERVO_CENTER_US, SERVO_CENTER_US,
};
static uint16_t servo_defaults[SERVO_COUNT] = {
    SERVO_CENTER_US, SERVO_CENTER_US, SERVO_CENTER_US, SERVO_CENTER_US,
};
static uint16_t servo_ramp_speed_us_s = SERVO_RAMP_DEFAULT_US_S;
static uint16_t servo_default_ramp_speed_us_s = SERVO_RAMP_DEFAULT_US_S;
static int64_t last_servo_command_us;
static TaskHandle_t crsf_task_handle;
static QueueHandle_t espnow_queue;
static volatile bool telemetry_peer_ready;
static uint16_t telemetry_sequence;
static int64_t last_telemetry_send_us;

static int16_t clamp_i16(int16_t value, int16_t minimum, int16_t maximum)
{
    if (value < minimum) {
        return minimum;
    }
    if (value > maximum) {
        return maximum;
    }
    return value;
}

static uint16_t read_u16_le(const uint8_t *data)
{
    return (uint16_t)data[0] | ((uint16_t)data[1] << 8);
}

static void write_u16_le(uint8_t *data, uint16_t value)
{
    data[0] = (uint8_t)(value & 0xFFU);
    data[1] = (uint8_t)(value >> 8);
}

static int16_t read_i16_le(const uint8_t *data)
{
    return (int16_t)read_u16_le(data);
}

static uint16_t crc16_ccitt(const uint8_t *data, size_t length)
{
    uint16_t crc = 0xFFFF;
    for (size_t i = 0; i < length; ++i) {
        crc ^= (uint16_t)data[i] << 8;
        for (int bit = 0; bit < 8; ++bit) {
            crc = (crc & 0x8000U) ? (uint16_t)((crc << 1) ^ 0x1021U) : (uint16_t)(crc << 1);
        }
    }
    return crc;
}

static uint8_t crc8_dvb_s2(const uint8_t *data, size_t length)
{
    uint8_t crc = 0;

    for (size_t i = 0; i < length; ++i) {
        crc ^= data[i];
        for (int bit = 0; bit < 8; ++bit) {
            crc = (crc & 0x80U) ? (uint8_t)((crc << 1) ^ 0xD5U) : (uint8_t)(crc << 1);
        }
    }
    return crc;
}

static uint32_t servo_pulse_to_duty(uint16_t pulse_us)
{
    return ((uint32_t)pulse_us * ((1U << 16) - 1U)) / SERVO_PWM_PERIOD_US;
}
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
